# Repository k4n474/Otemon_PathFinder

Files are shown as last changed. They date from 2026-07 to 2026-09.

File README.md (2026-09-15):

# Otemon PathFinder

<p align="center">
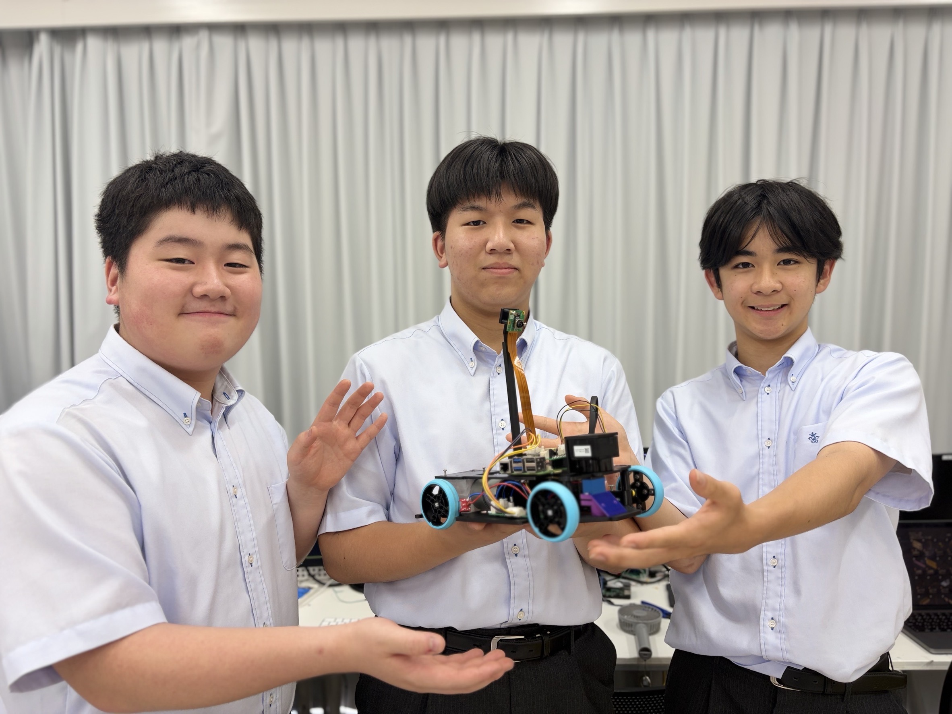
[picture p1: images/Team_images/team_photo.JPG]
team_photo
  
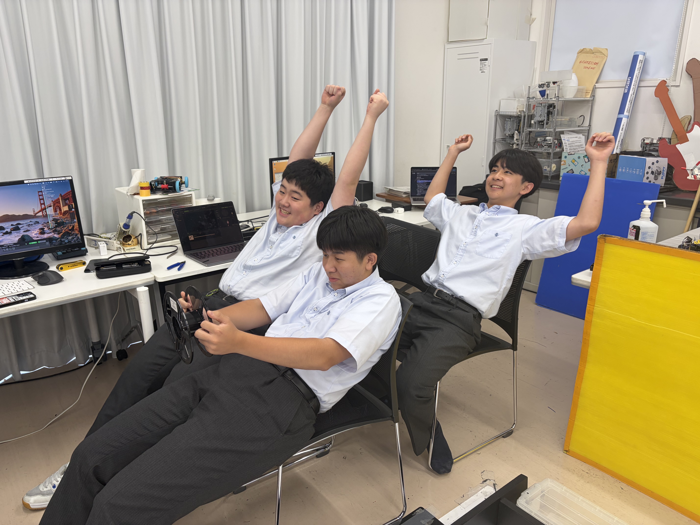
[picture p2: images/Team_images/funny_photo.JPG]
funny_photo
  
</p>

Meet the Engineers

(👈Left) [Name] led the mechanical design, crafting custom 3D-printed chassis parts, high-precision gears, and robust structural mechanisms.

(🫵Center) [Name] spearheaded the electrical architecture, designing custom PCBs, optimizing power management, and selecting core components.

(👉Right) [Name] drove software development and computer vision, building algorithm, calibrating sensor inputs, and writing code to keep the robot fully autonomous.

- [Hardware](#hardware)

  - [Photos of Robots](#photos-of-robots)

  - [Videos](#videos)

  - [Main Components](#main-components)

  - [Controller](#controller)

  - [LiDAR](#lidar)

  - [Camera](#camera)

  - [Chassis](#chassis)

  - [Steering Mechanism](#steering-mechanism)

  - [Electrical System](#electrical-system)

- [Software](#software)

  - [Open Challenge](#open-challenge)

  - [Obstacle Challenge](#obstacle-challenge)

# Hardware

## Photos of Robots

<p align="center">
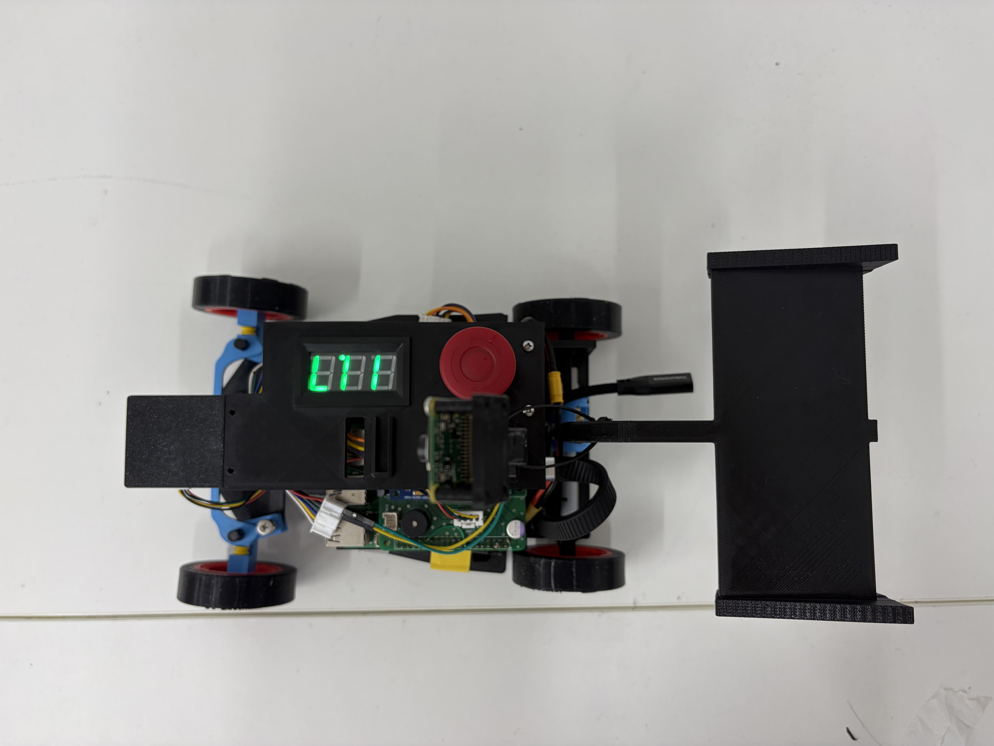
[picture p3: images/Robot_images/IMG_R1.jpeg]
Robot1
  
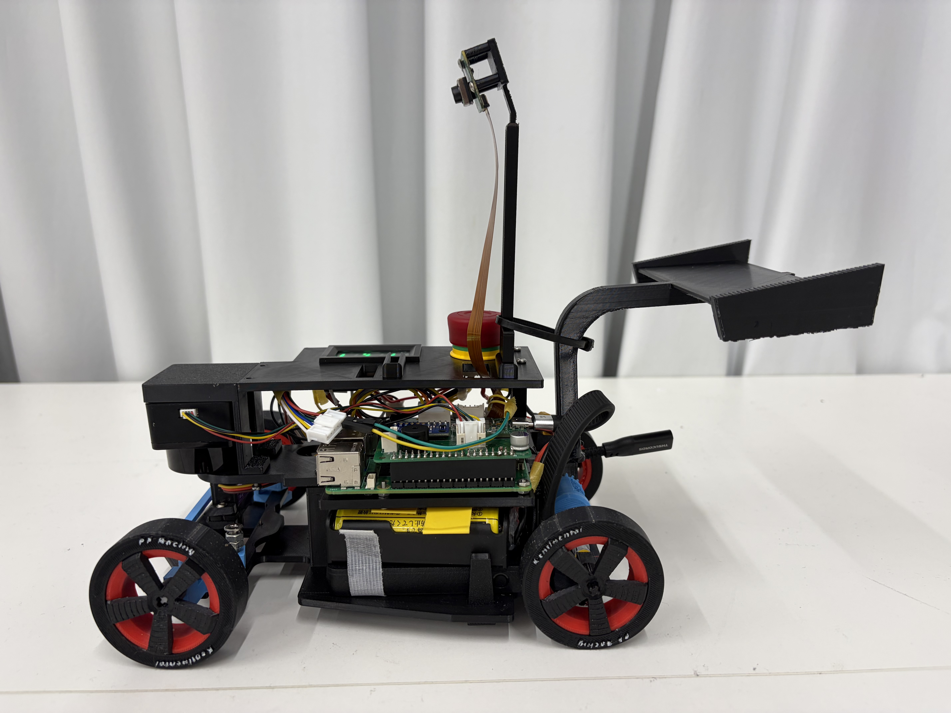
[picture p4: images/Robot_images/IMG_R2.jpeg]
Robot2
  
</p>

<p align="center">
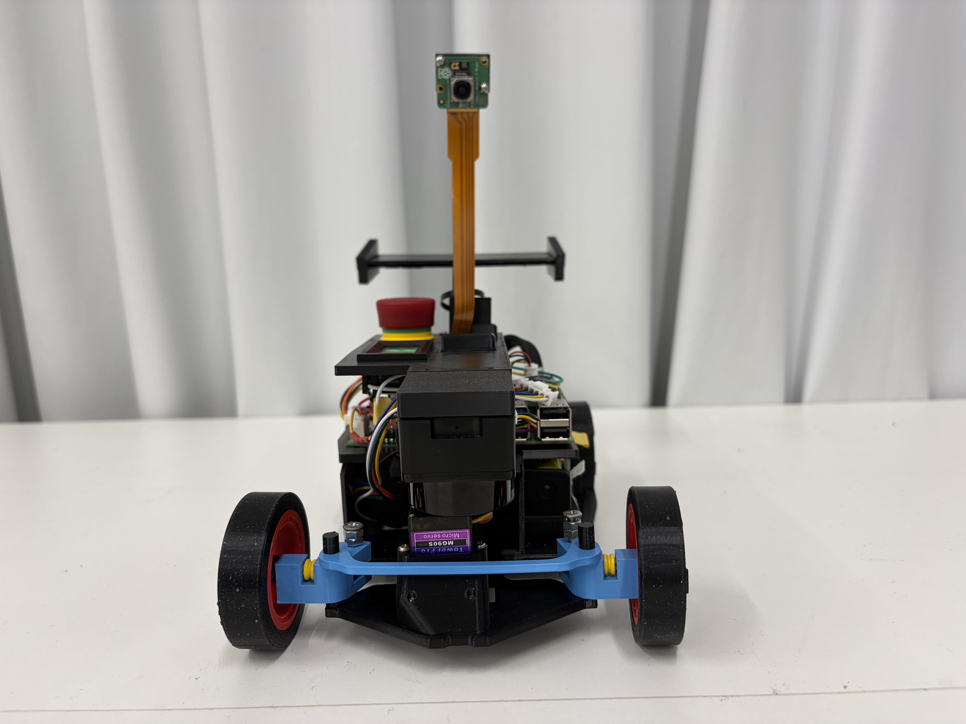
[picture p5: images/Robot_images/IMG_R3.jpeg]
Robot3
  
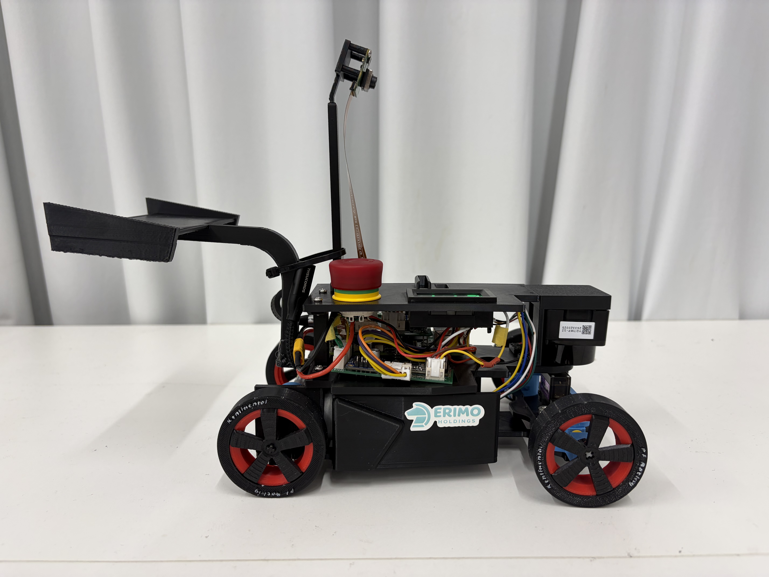
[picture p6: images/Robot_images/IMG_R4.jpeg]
Robot4
  
</p>

<p align="center">
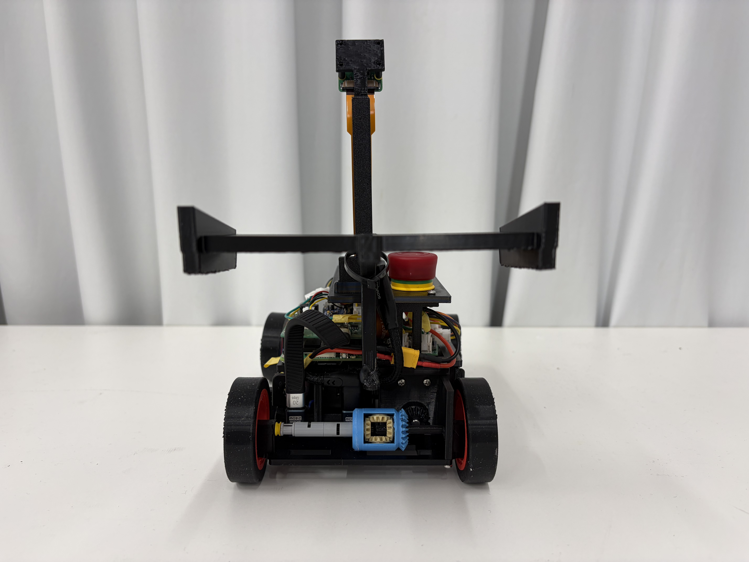
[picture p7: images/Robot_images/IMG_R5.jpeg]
Robot5
  
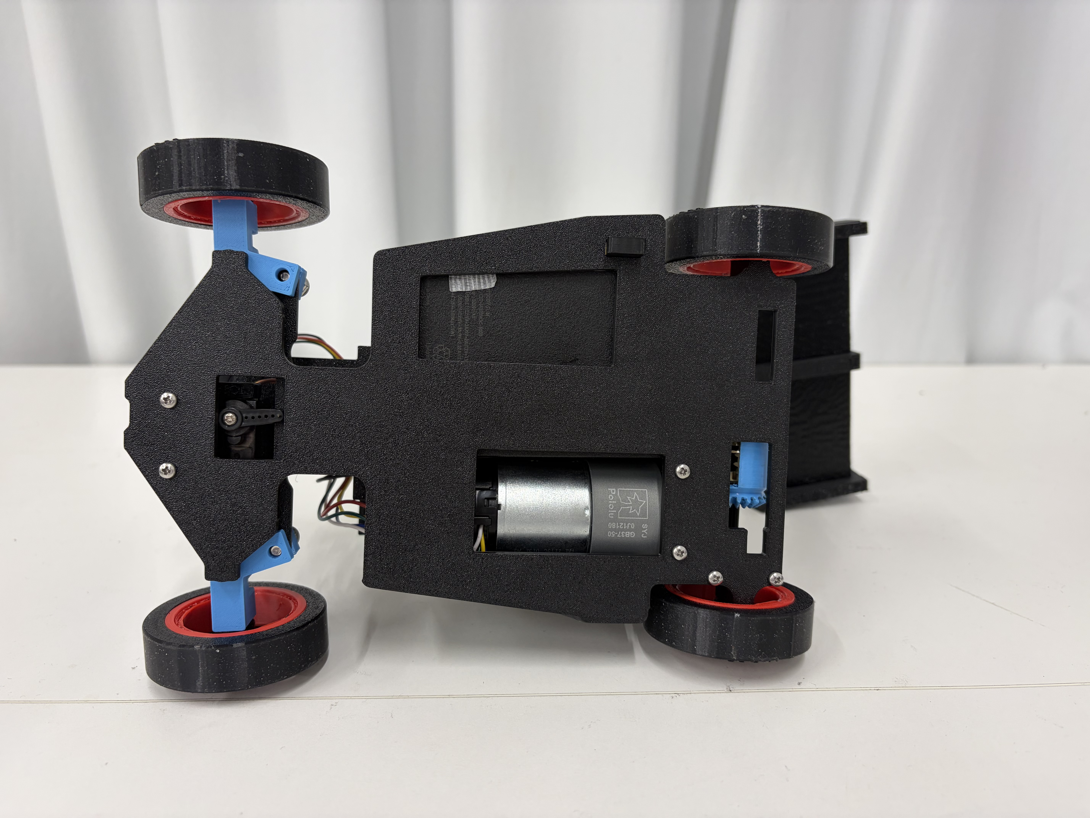
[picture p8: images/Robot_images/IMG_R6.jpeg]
Robot6
  
</p>

<p align="center">
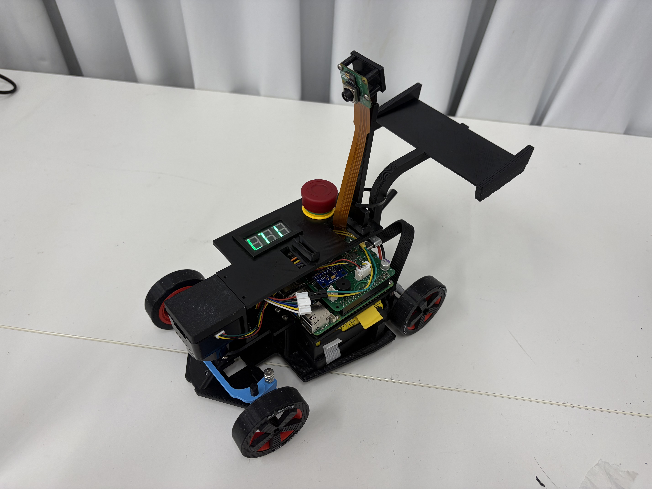
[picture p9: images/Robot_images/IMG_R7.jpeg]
Robot7
  
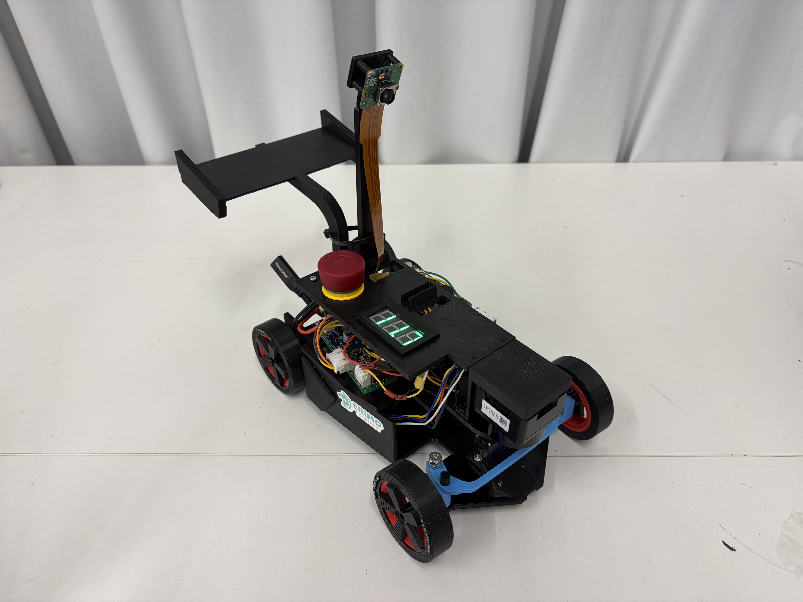
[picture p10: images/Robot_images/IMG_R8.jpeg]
Robot8
  
</p>

<p align="center">
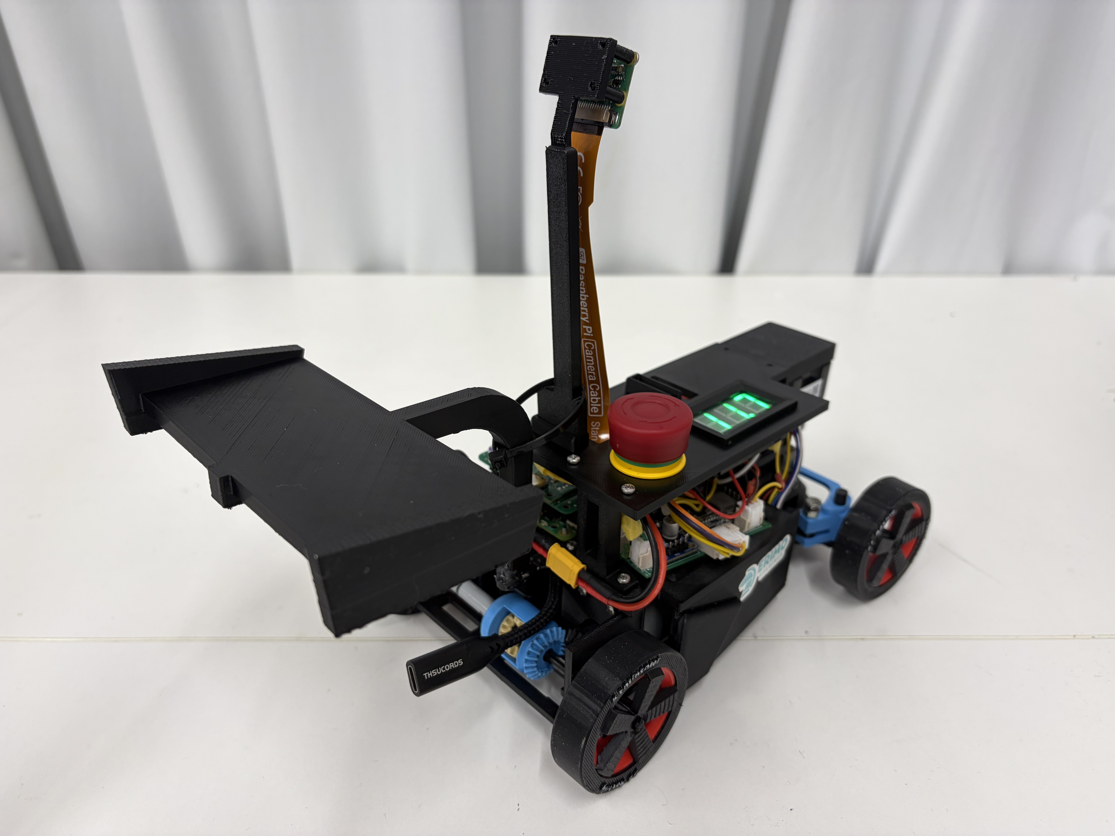
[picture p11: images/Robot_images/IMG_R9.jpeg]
Robot9
  
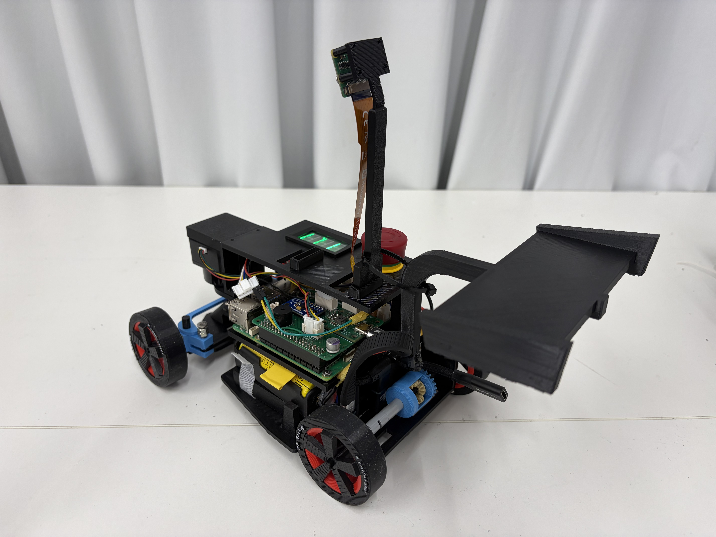
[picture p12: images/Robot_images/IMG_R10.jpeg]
Robot10
  
</p>

## Videos
<table align="center">
  <tr>
    <td align="center" width="50%">
      <a href="https://youtu.be/6eP5m4vgBc8">
        <br>
        <sub><b>Open_ChallengeCounter-clockwise</b></sub>
      </a>
    </td>
    <td align="center" width="50%">
      <a href="https://youtu.be/HAOU7pk2X0k">
        <br>
        <sub><b>Open_Challenge_clockwise</b></sub>
      </a>
    </td>
  </tr>
  <tr>
    <td align="center" width="50%">
      <a href="https://youtu.be/kFfds26Y_WM">
        <br>
        <sub><b>Obstacle_ChallengeCounter-clockwise</b></sub>
      </a>
    </td>
    <td align="center" width="50%">
      <a href="https://youtu.be/7NU6L5QEaes">
        <br>
        <sub><b>Obstacle_Challenge_clockwise</b></sub>
      </a>
    </td>
  </tr>
</table>

## Main Components

| Category| Model | 
|---|---|
| Controller | Raspberry Pi 5 |
| Subcomputer| Seeed XIAO RP2040 |
| LiDAR | T-mini Plus 12 |
| Camera | Camera Module 3 Wide |
| DC Motor | Pololu 50:1 Metal Gearmotor 37Dx70L mm 12V with 64 CPR Encoder (Helical Pinion) |
| Motor Driver | DRV8871 | 
| Servo Motor | MG90S |
| USB PD Power Supply | PWR-USBDCDC5 |
| Connectors | JST XA Series　|

## Controller

Our robot uses a **Raspberry Pi 5** as its main controller.

To accurately recognize objects, the robot must process camera images while simultaneously handling data from multiple sensors, including a LiDAR and a gyroscope. Therefore, we selected the Raspberry Pi because of its high computing performance and excellent expandability.

Unlike a conventional microcontroller, the Raspberry Pi is a compact computer that runs Linux. As a result, it is less suitable for applications requiring strict real-time control, such as motor control, and it also consumes more power. However, its powerful processing capability allows it to handle computationally intensive tasks, including image processing and LiDAR point cloud processing. Since these functions are essential for our robot, we concluded that the Raspberry Pi was the most suitable controller.

At the beginning of development, we used a **Raspberry Pi 4**. However, image processing required more computational power than expected, making real-time control difficult in some situations. After upgrading to the Raspberry Pi 5(Jun. 2026), image processing became significantly faster, resulting in much more stable driving performance.

We also adopted an **RP2040** as a sub-controller for motor control.

Because the Raspberry Pi 5 runs Linux, when we command it (for example, changing PWM values or reading encoders in Python), many processes such as LiDAR processing, camera processing, and communication are running simultaneously. As a result, **the processing timing can drift slightly**. Considering this and maintainability, we decided to offload motor control to the RP2040.

## LiDAR

Our robot uses a **LiDAR** for wall detection, distance measurement, and wall following.

We initially considered using ultrasonic sensors. However, ultrasonic sensors can only measure distance in a single direction, whereas the LiDAR can obtain distance information from almost the entire surrounding area, although part of its field of view is blocked by components such as the Raspberry Pi. This allows the robot to detect obstacles in front while simultaneously measuring the distances to both side walls, enabling more accurate self-localization.

One of the greatest challenges during development was designing an algorithm capable of accurately detecting walls using LiDAR point cloud data. In addition, because the robot must process a large amount of distance data in real time, optimizing the processing speed was also a major challenge. Through repeated testing and refinement, we continuously improved both the algorithm and the software until the current system was completed.

Currently, for each full rotation of LiDAR data (angle and distance), we remove points behind the robot and points with abnormal distances, and convert points within 3 m into planar coordinates. Then, using RANSAC, we search for line-shaped point sets: we randomly choose two points to form a line, collect points within 50 mm of that line, and repeat this 100 times, selecting the line that gathers the most points. We then refine the line using the gathered points, and treat a segment as a wall if it has at least 10 points and a length of at least 100 mm. Up to four walls are detected. If the gap between points exceeds 250 mm, we treat them as separate clusters.
Among the detected walls, we select up to the three walls with the highest number of points and classify them into right wall / front wall / left wall based on the direction of the perpendicular from the LiDAR to the wall. If three walls are available, we assign right–front–left in order of angle. If only one or two are available, we assign roles based on which reference direction they are closest to. However, to be used as a front wall, the wall must be at least 500 mm long. Distances to walls are computed using the perpendicular distance from the LiDAR to the wall line, and we follow whichever side wall is longer. This recognition is performed every rotation, and we do not build a map by accumulating past point clouds.

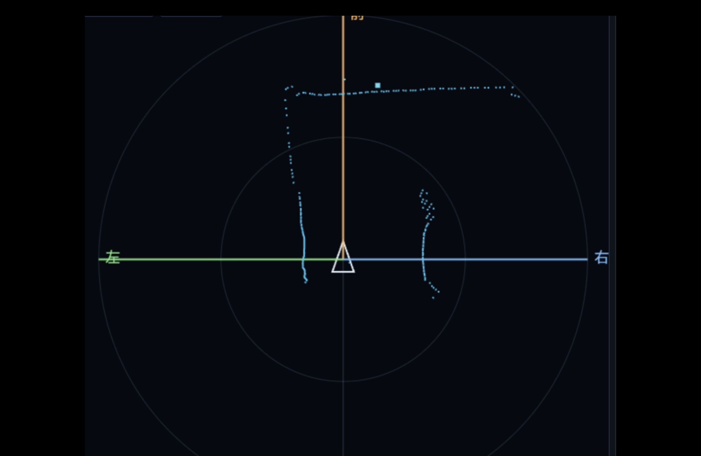
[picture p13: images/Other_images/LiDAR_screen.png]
LiDAR

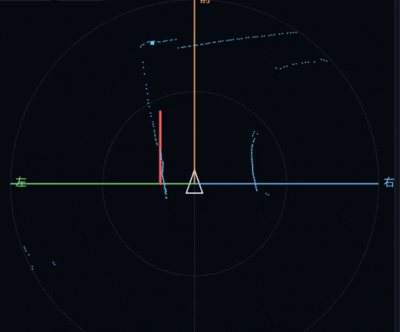
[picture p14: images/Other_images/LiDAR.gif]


## Camera

At the beginning of development, we used a **HuskyLens** because it allowed us to implement object recognition relatively easily. However, we found limitations in both recognition accuracy and flexibility, so we decided to develop our own image recognition program from scratch.

We use a **Raspberry Pi Camera Module 3 Wide** because of its excellent compatibility with the Raspberry Pi and its ability to capture images at high speed. Initially, we used the standard **Raspberry Pi Camera Module 3**, but its horizontal field of view was only about **66°**, causing obstacles to occasionally move outside the camera image. As a result, reliable obstacle avoidance was difficult. After replacing it with the **Camera Module 3 Wide**(Jun. 2026), the horizontal field of view increased to approximately **102°**, allowing the robot to detect obstacles much more reliably.

The captured RGB image is first converted into the **HSV color space**. HSV consists of **Hue (color), Saturation, and Value (brightness)**, and is less affected by changes in lighting conditions than RGB. This enables the robot to distinguish red and green objects more reliably by using hue information.

<p align="center">
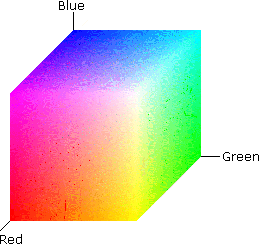
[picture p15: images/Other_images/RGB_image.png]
rgb
  
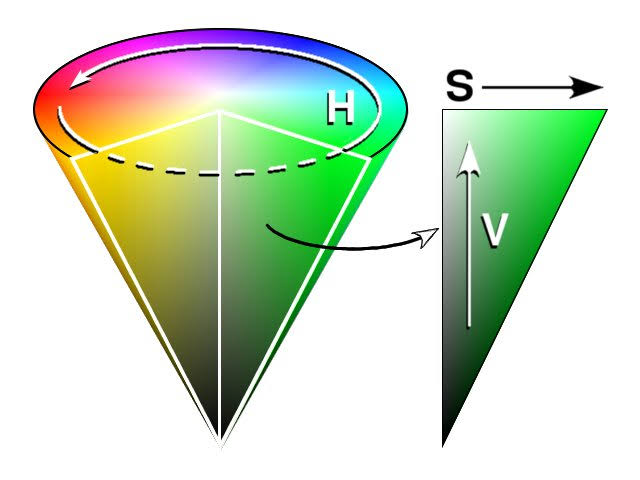
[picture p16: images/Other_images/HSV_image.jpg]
hsv
  
</p>

After the conversion, separate color masks are applied to the red and green objects, followed by binary thresholding to extract only the target objects. Contour detection is then performed to obtain the coordinates of the four corners of each object. However, with this approach alone, the system also recognized red and blue objects outside the coat. Therefore, we modified the system so that it would recognize the coat using the camera and treat only objects overlapping that area as obstacles(Aug. 2026).Using those object coordinates, we determine the objects’ positions and colors, and use the resulting information for navigation.Also, since part of the robot appears in the camera's field of view, the program is configured to skip image recognition in that area.

The court is detected using the same approach as object detection, by applying a white color mask.

<p align="center">
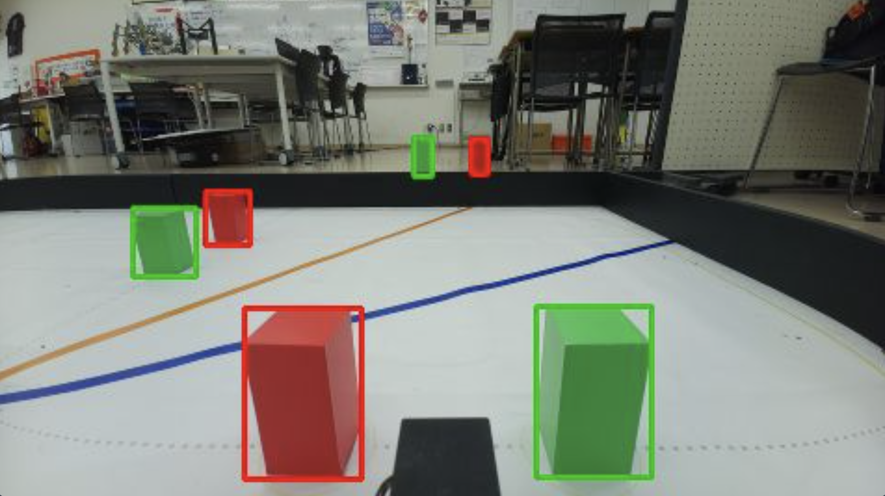
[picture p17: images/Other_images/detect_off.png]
off
  
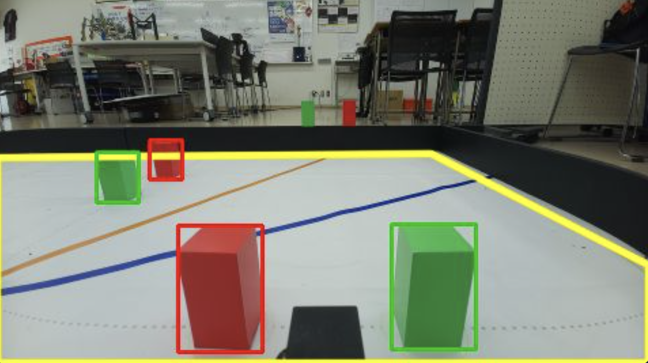
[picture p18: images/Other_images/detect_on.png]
on
  
</p>

In addition, the camera recognizes a blue line to count the number of laps.

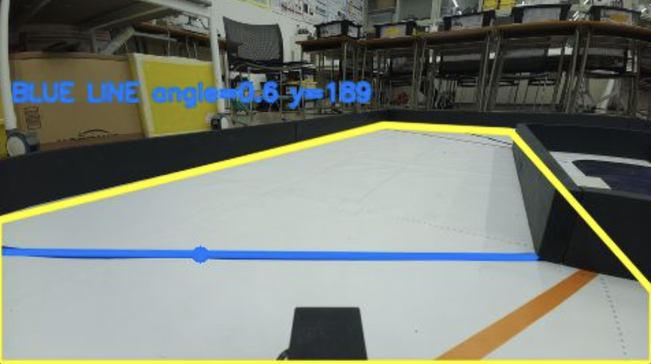
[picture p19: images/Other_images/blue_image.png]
Camera


## Chassis

Most of the robot’s mechanical components, excluding electronic parts, were designed by our team and manufactured using **3D printers**. This allowed us to create custom parts that would have been difficult or impossible to produce using commercially available components, enabling a structure optimized specifically for our robot.

We selected **ABS** as the printing material. At the beginning of development, we used PLA and PETG because they were easier to print, but we decided to switch to ABS due to durability concerns(Aug. 2026).

We use a **Bambu Lab X2D** for manufacturing. At the beginning of development, all parts were produced using a **Bambu Lab A1**. However, the A1 could not print ABS, so we introduced the X2D to enable ABS printing(Jul. 2026). In addition, the **Bambu Lab X2D** improved printing speed and quality.

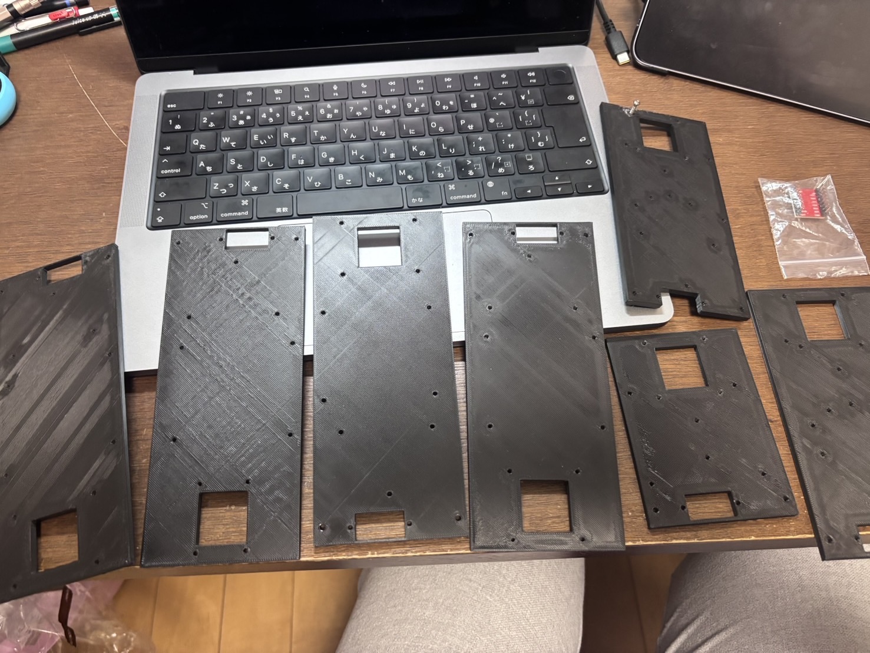
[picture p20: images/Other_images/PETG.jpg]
PETG

This is the PETG chassis from an early version of our robot. All parts have been fine-tuned.

## Steering Mechanism

Initially, our robot used a conventional steering mechanism. However, it could not achieve sufficient turning performance when negotiating sharp corners.

To improve cornering performance, we adopted an **Ackermann steering mechanism** for the front wheels.(Jun. 2026) This allows each front wheel to follow the appropriate turning radius while sharing the same turning center, reducing tire slip and enabling smoother cornering.

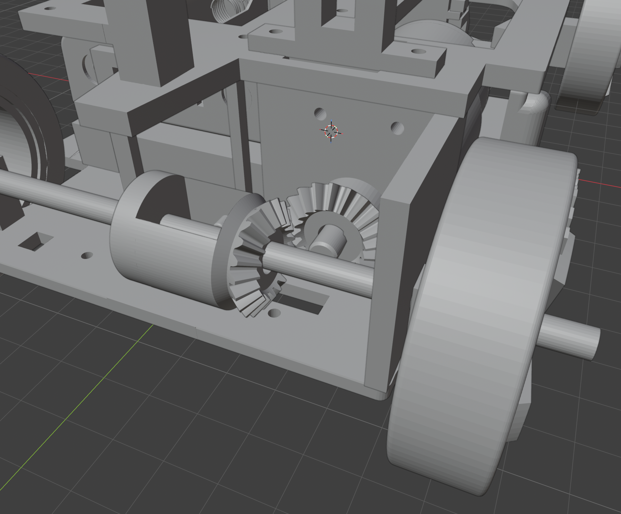
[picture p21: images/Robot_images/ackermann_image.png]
Ackermann


In addition, we selected **high-torque drive motors**, providing sufficient driving force even under heavy loads and ensuring stable vehicle movement.

A **differential gear** is also installed on the rear axle.(Jun. 2026) During cornering, it absorbs the rotational speed difference between the left and right wheels, reducing mechanical stress on the tires and enabling smoother turns.

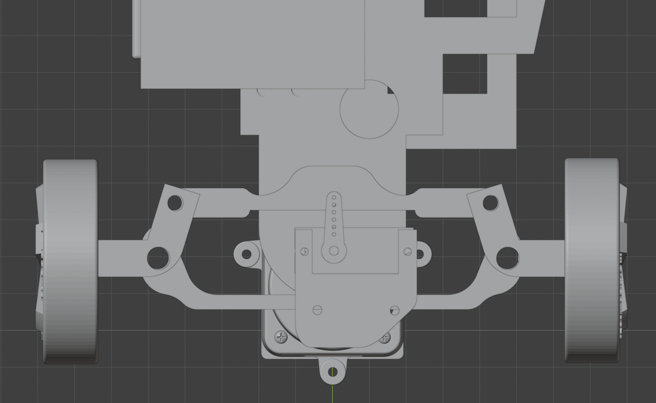
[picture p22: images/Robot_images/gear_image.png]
Gear


## Electrical System

To prevent voltage drops and electrical noise generated by the drive motors from affecting the control system, our robot uses **separate power supplies for the drive system and the control system.**

The drive motors are powered by a battery pack consisting of **three 18650 lithium-ion batteries connected in series**. Since the fully charged battery voltage is approximately **12 V**, the motors are powered directly without additional voltage conversion.

When the voltage drops below 11 V, the robot’s movement becomes weaker. Therefore, we installed a voltmeter module on the robot to monitor the voltage(Sep. 2026).

In addition, to allow the robot to stop immediately in dangerous situations (for example, when it starts malfunctioning), we added an emergency stop button to the motor power circuit so that the robot can be stopped physically(Sep. 2026).

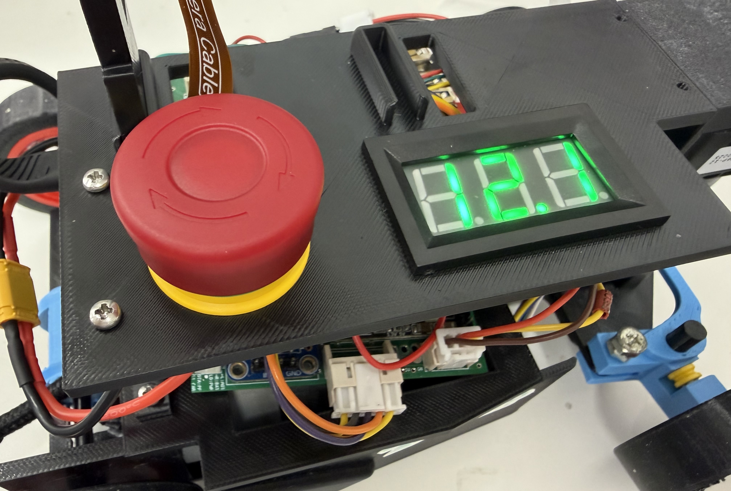
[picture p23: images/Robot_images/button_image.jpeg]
Stop_button


The steering servo is powered through a **buck converter (DC-DC converter)**, which steps the voltage down to **5 V** and provides a stable power supply.

The Raspberry Pi is powered by a **5,000 mAh USB Power Delivery (PD) power bank**. Separating the motor and control power supplies reduces malfunctions caused by voltage fluctuations and electrical noise, significantly improving the overall stability of the robot.

To simplify wiring as additional functions were added, we also designed and manufactured a **custom Raspberry Pi HAT board**(Jun. 2026). This board organizes the wiring, simplifies assembly and maintenance, and improves the overall maintainability of the robot.

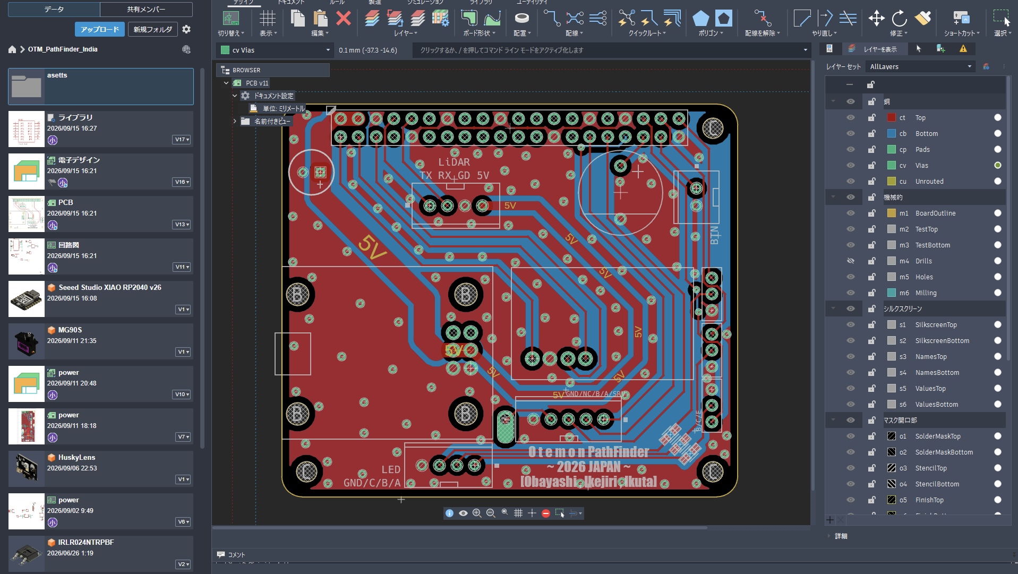
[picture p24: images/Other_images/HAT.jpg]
HAT


### Overall Wiring

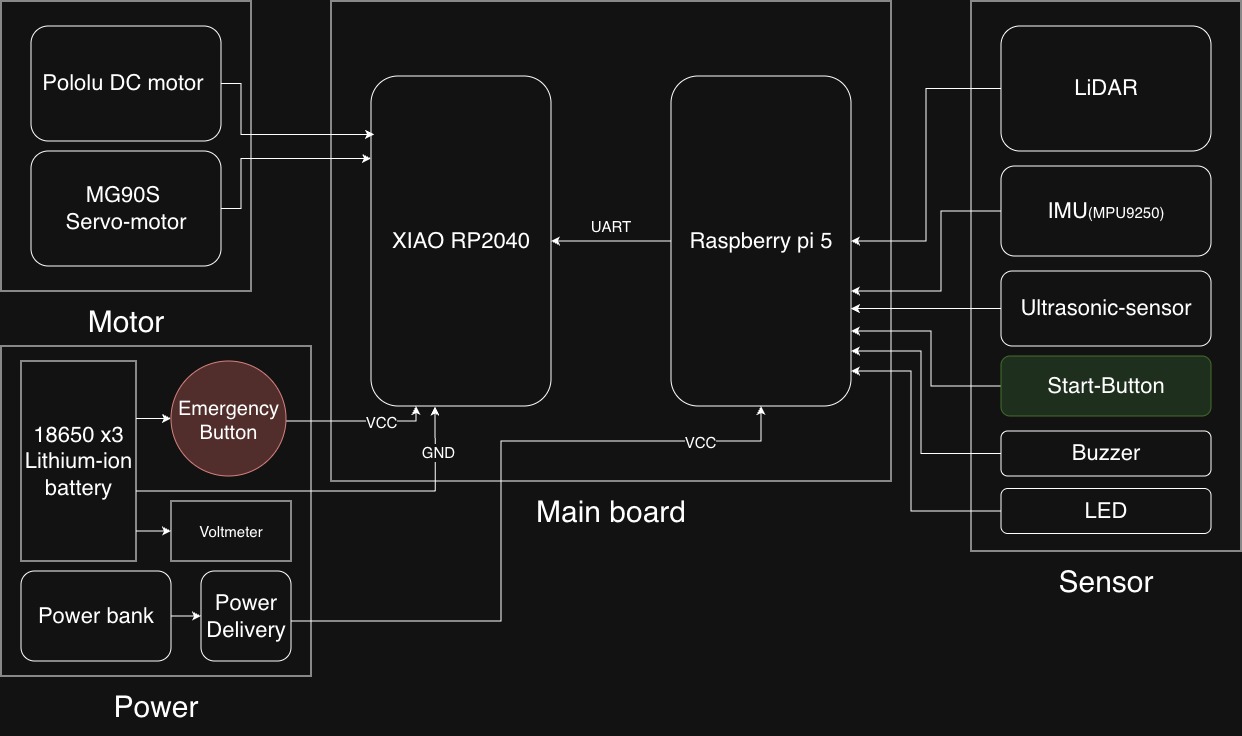
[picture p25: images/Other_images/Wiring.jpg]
Wiring


# Software

## Open Challenge

In the **Open Challenge**, the robot navigates primarily using **LiDAR**. As described earlier, we selected LiDAR because it provides distance information from almost the entire surrounding area, allowing the robot to perceive its environment with high accuracy.

During operation, the robot continuously measures the distances to the front wall and both side walls using the LiDAR. The distances to the side walls are used as the input for a **PID controller**, enabling the robot to maintain a stable position near the center of the course. In addition, at the start the robot detects the left and right walls using LiDAR, and leveraging the characteristic that the field’s inner wall is shorter than the outer wall, it decides which wall to follow based on wall length.

Just before a corner, when the distance to the front wall falls below a predefined threshold, the robot determines that it has reached the corner. It then measures the angle of the front wall with LiDAR and determines (with a gyroscope) the angle that becomes parallel to the front wall while performing the turn. This feedback-based control allows the robot to achieve stable and accurate cornering.

## Obstacle Challenge

In the **Obstacle Challenge**, the robot uses a **Raspberry Pi Camera** to detect obstacles and control its movement accordingly.

The obstacle-avoidance loop begins by checking whether an object is detected by the camera. If no object is detected, the robot repeatedly runs `find_obj` until an object is found. `find_obj` basically steers in the same direction as the lap direction while moving forward until an object is detected. However, if a wall is detected using the line at the bottom of the camera image, it interrupts this behavior and steers away from the wall until the wall is no longer detected.

Once an object is detected, the robot starts `avoid_obj` to avoid the closest object. The closest object is defined as the one appearing lowest in the image.

In `avoid_obj`, the robot avoids **red** objects by going to the right and **green** objects by going to the left. If the object being avoided disappears from the camera image and no other objects are detected, the robot returns to `find_obj`. If other objects are still detected, the robot continues `avoid_obj`, and the next closest object becomes the new target without leaving the function.

For example, if the object is green, the robot draws a line from the bottom-right corner of the image to the center of the green object, and uses PD control on the steering so that the angle inside that line matches a preset value. During `avoid_obj`, another line is drawn from the bottom-right corner to a point slightly left of the object’s left edge (object width × 3 px). This line corresponds to the path of the robot’s right edge while avoiding the object. If this line overlaps with a wall, the robot would collide with the wall if it continued, so it temporarily stops the avoidance PID control and steers left until the wall no longer overlaps with the wall-detection line. (For red objects, the left/right behavior is reversed.)

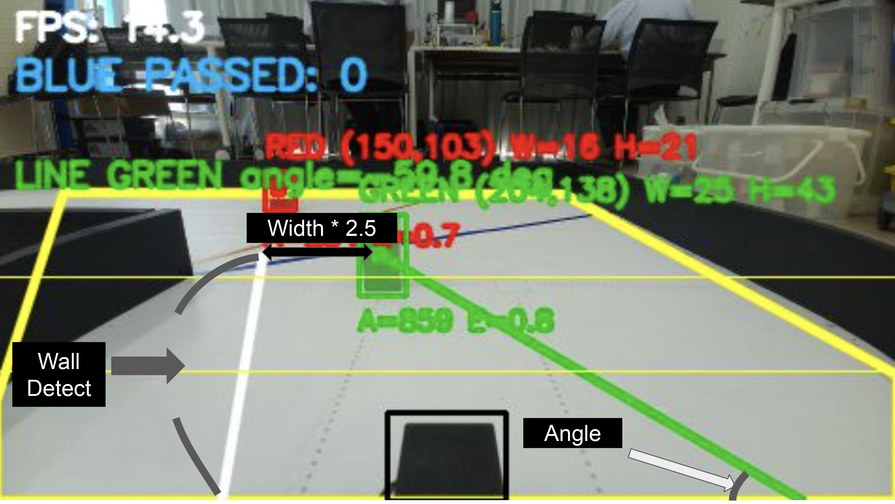
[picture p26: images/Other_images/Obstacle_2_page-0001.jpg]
Obstacle_image

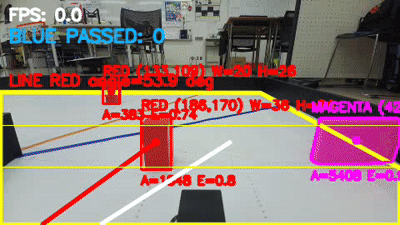
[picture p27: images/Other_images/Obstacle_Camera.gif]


Lap counting is done by counting how many times the blue line is detected. When the blue line transitions from detected to not detected, the lap count is incremented by 1. For a few seconds after detecting the blue line, detections are ignored to prevent false double-counting when the same line briefly disappears and reappears in the camera view.

Since our robot is relatively large, it often hits the wall when starting and when parking. As a result, the start succeeded only 7 out of 10 times and parking succeeded only 4 out of 10 times, which corresponds to success rates of 70% and 40%, respectively. Considering that the scores are 7 points for starting and 15 points for parking, we concluded that it is not worth attempting them at these success rates, and we decided to give up on starting and parking.

### Flowchart
<p align="center">
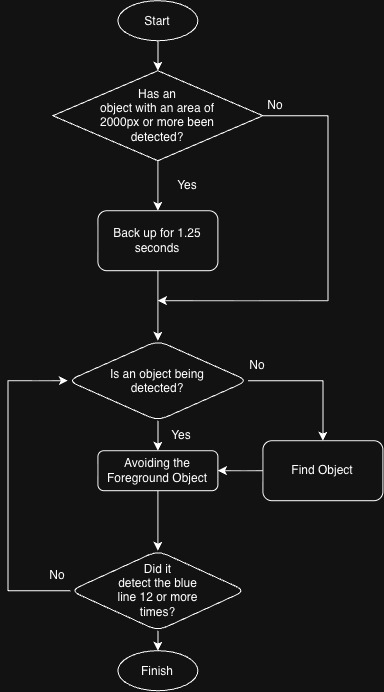
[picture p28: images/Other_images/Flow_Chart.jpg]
Flow_Chart
  
</p>

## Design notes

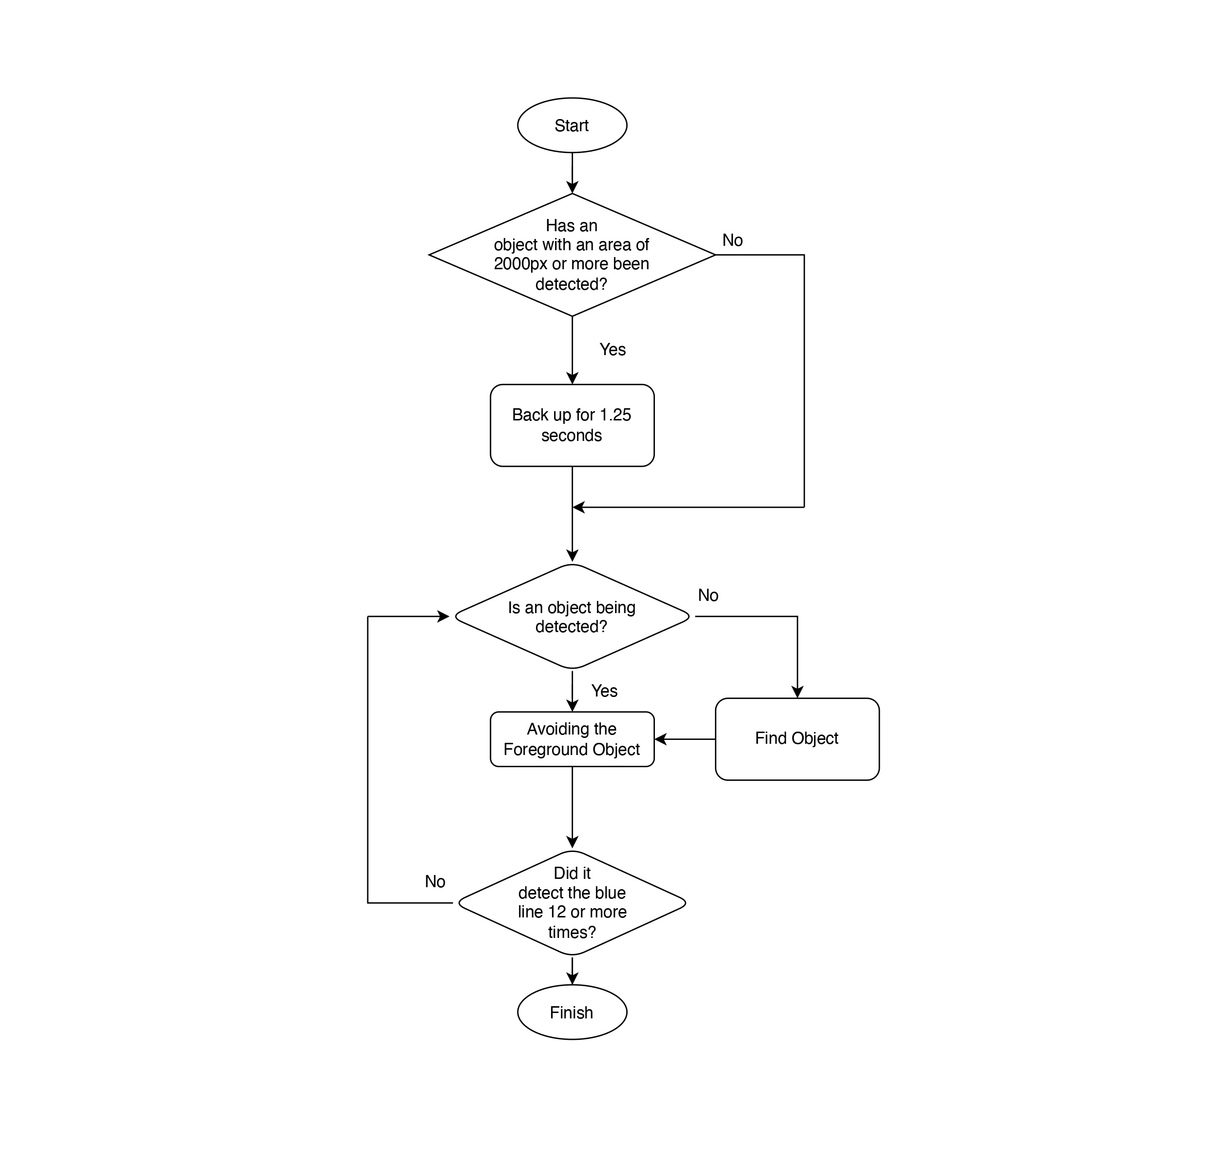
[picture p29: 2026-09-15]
images/Other_images/flow_chart_page-0001.jpg

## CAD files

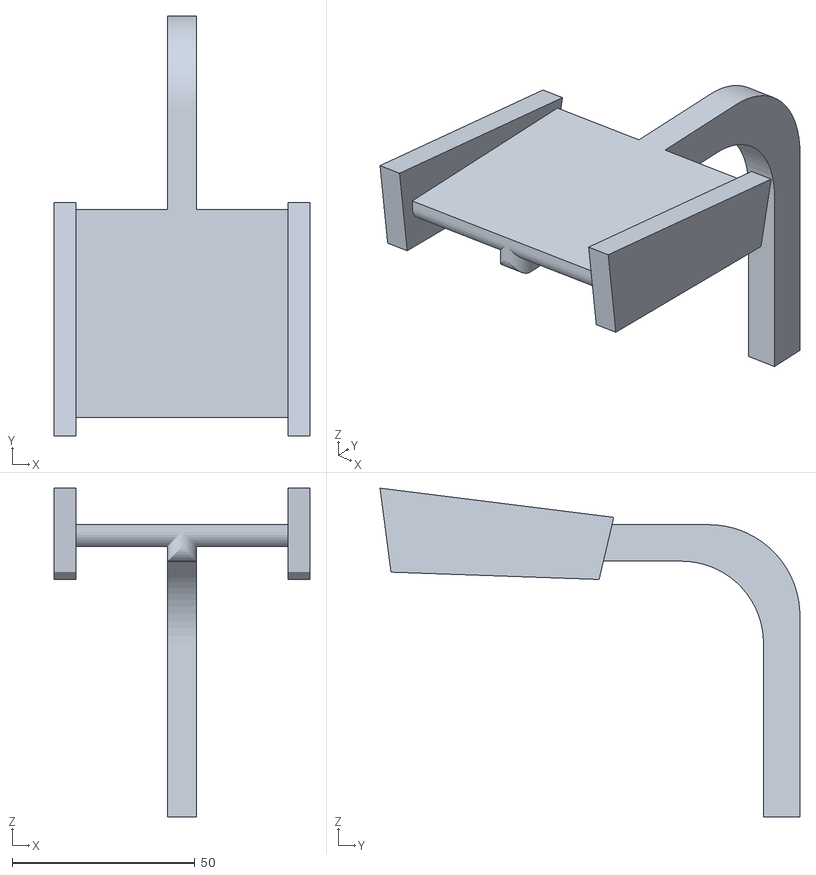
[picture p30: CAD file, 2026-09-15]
CAD/GTWing.stl
70.0 x 115.0 x 90.0

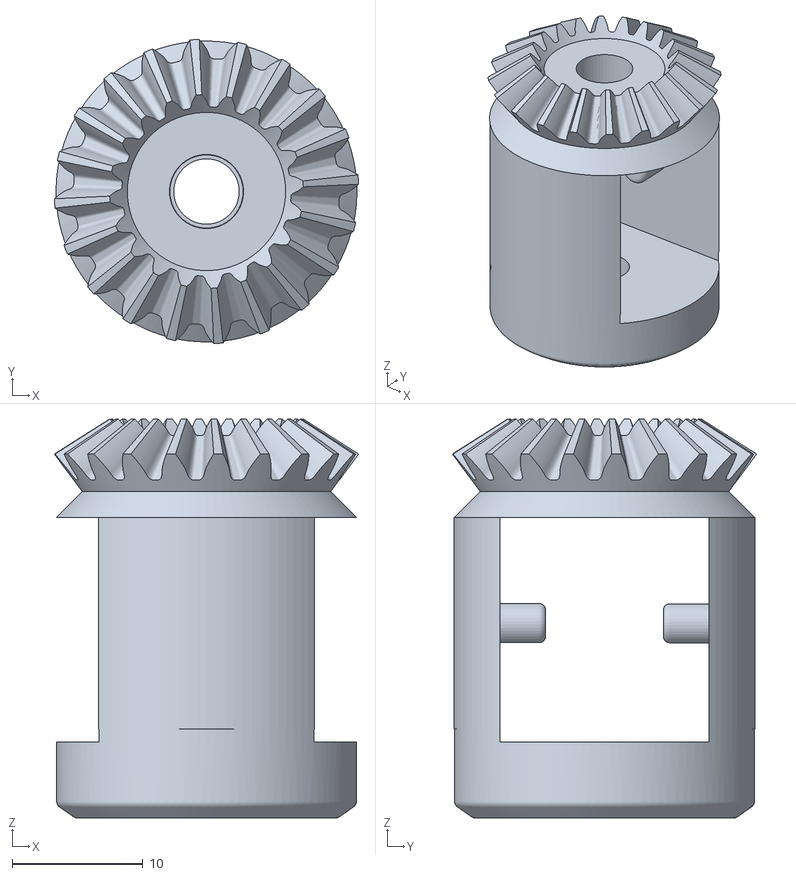
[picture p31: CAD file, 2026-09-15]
CAD/DiffinitialGear.stl
23.3 x 23.3 x 30.5

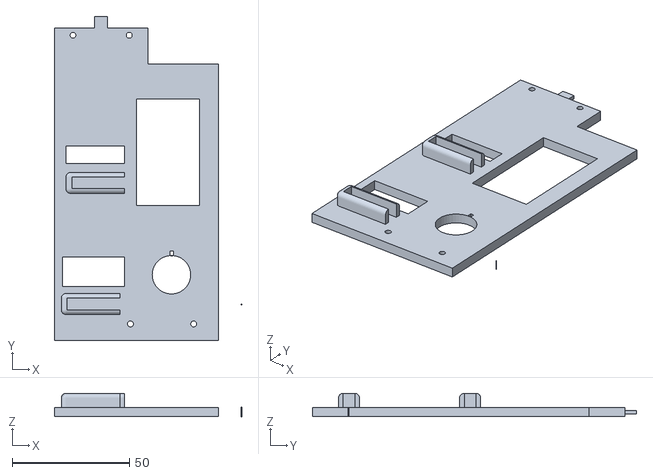
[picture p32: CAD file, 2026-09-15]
CAD/sansoume.stl
80.0 x 138.3 x 10.0

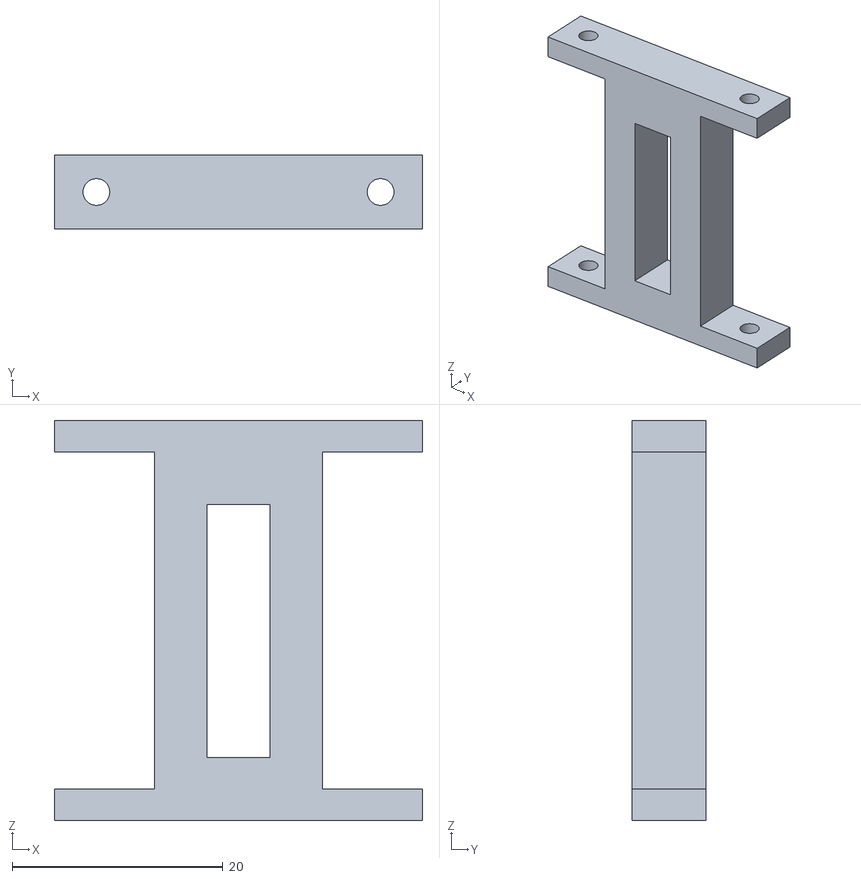
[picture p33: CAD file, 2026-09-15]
CAD/sasae.stl
35.0 x 7.03 x 38.0

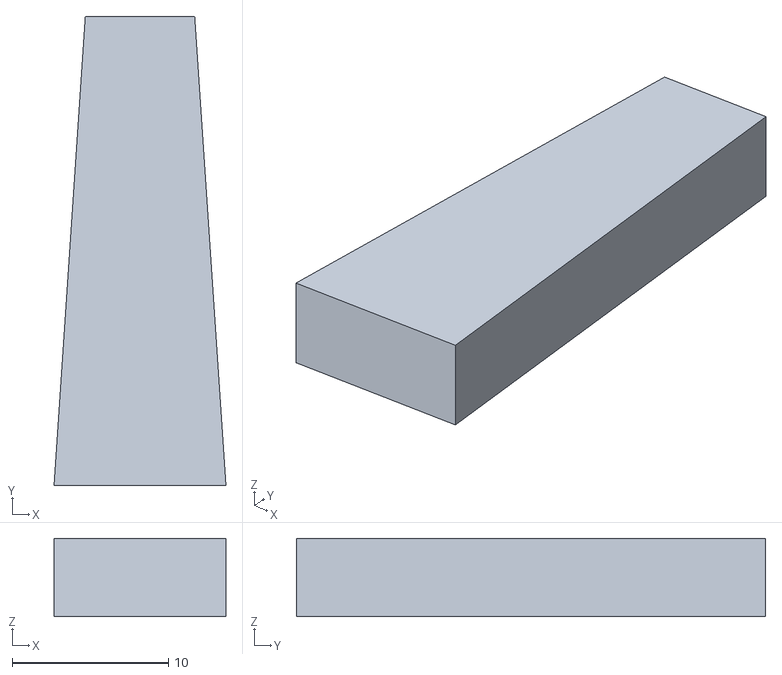
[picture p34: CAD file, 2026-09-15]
CAD/Stoper.stl
11.0 x 30.0 x 5.00

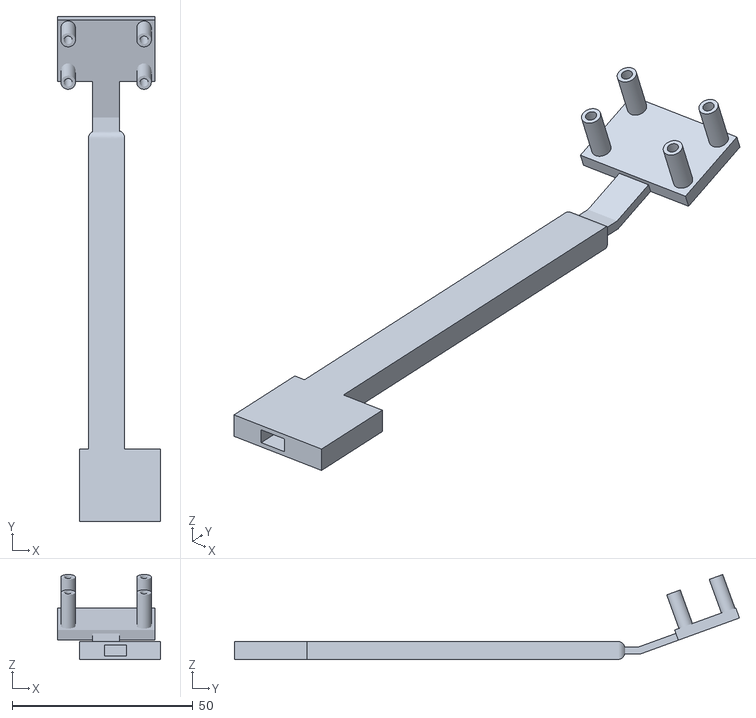
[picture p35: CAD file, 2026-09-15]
CAD/Camera.stl
28.6 x 139.7 x 23.5

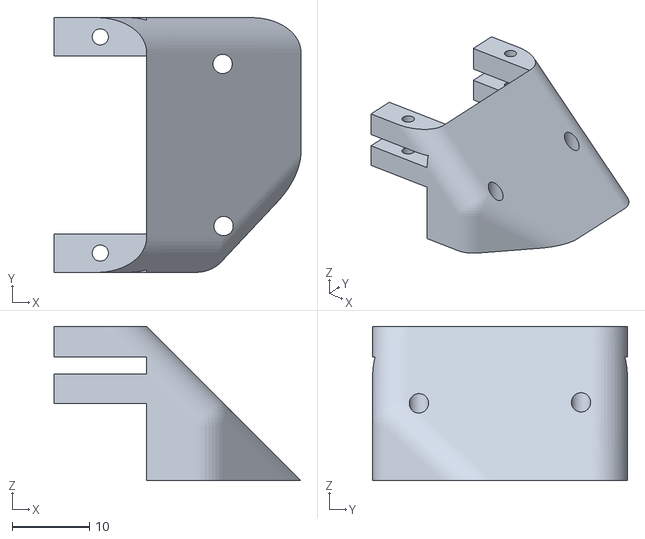
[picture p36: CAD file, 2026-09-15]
CAD/Servo-Mount.stl
32.0 x 33.0 x 20.0

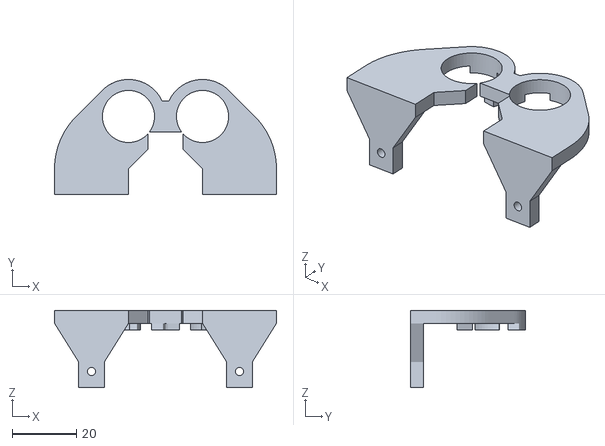
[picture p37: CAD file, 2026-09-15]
CAD/Ultra sensor.stl
69.0 x 35.8 x 24.0

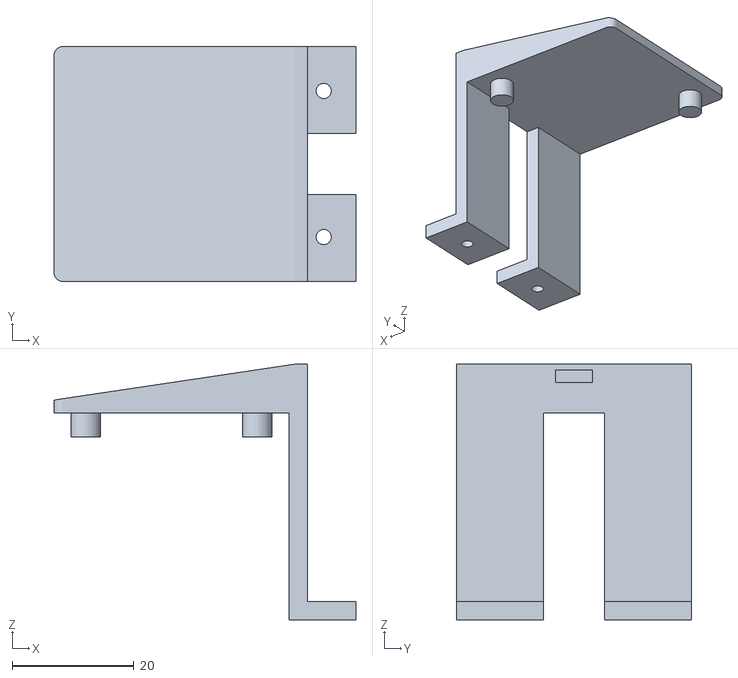
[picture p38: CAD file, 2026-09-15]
CAD/LiDARー.stl
49.6 x 38.6 x 42.0

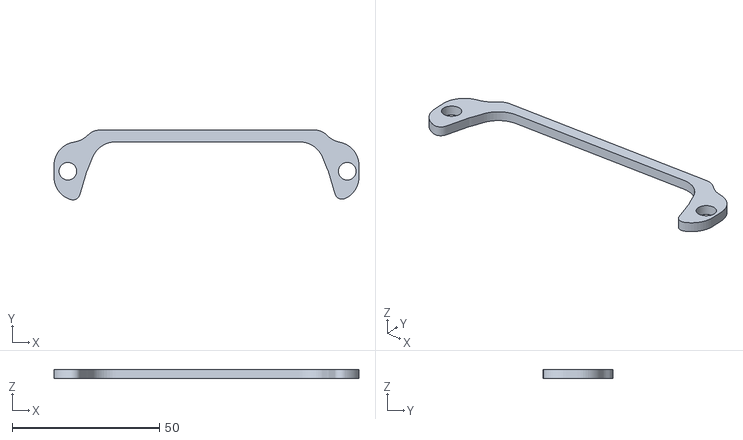
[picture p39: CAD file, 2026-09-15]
CAD/Zenrin dome.stl
103.7 x 23.8 x 3.00

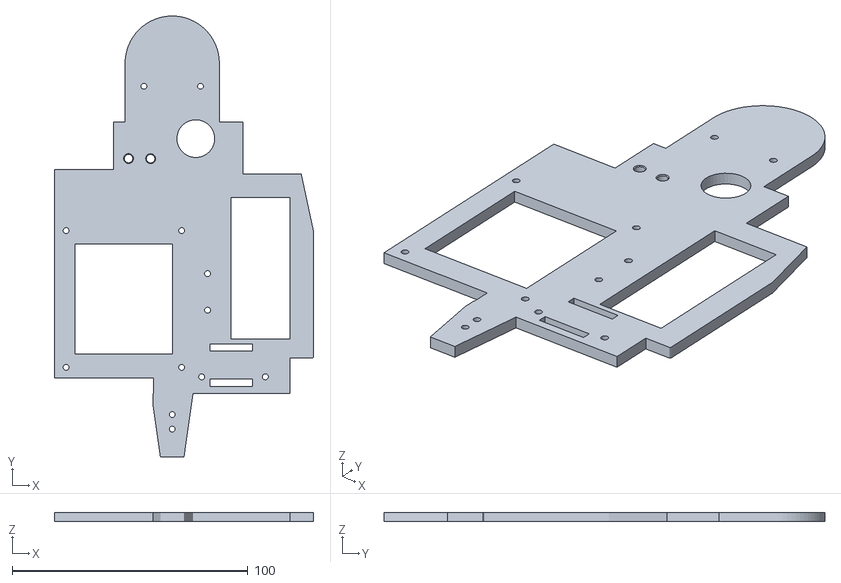
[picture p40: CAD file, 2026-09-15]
CAD/nisoume.stl
110.0 x 187.0 x 4.00

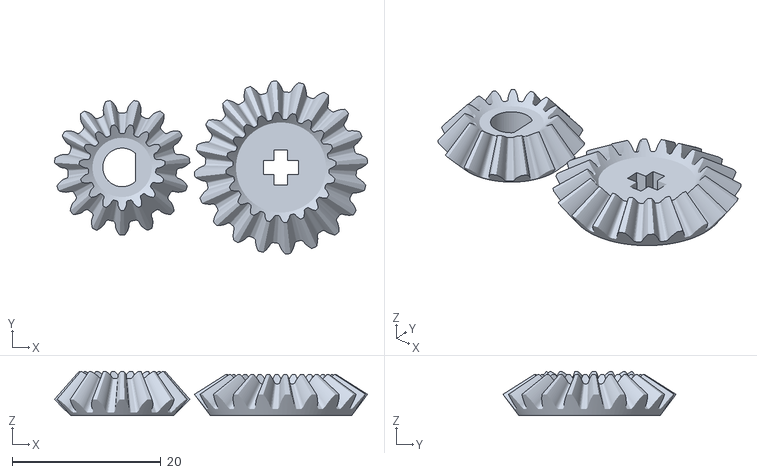
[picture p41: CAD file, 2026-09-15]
CAD/Gear.stl
42.1 x 23.3 x 5.95

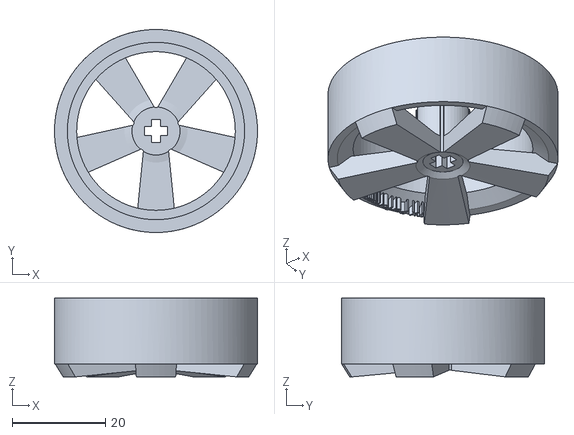
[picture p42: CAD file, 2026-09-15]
CAD/Wheel.stl
43.5 x 43.5 x 16.9

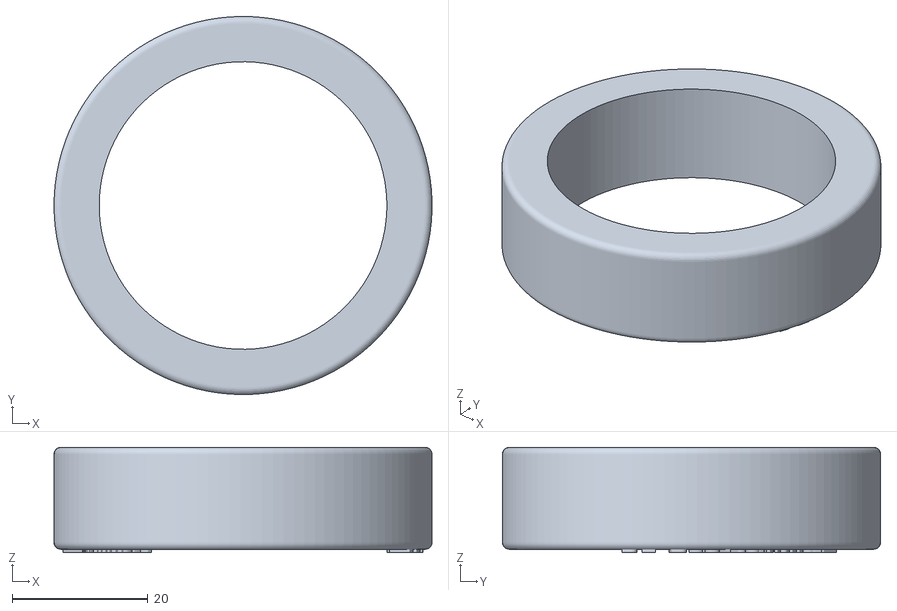
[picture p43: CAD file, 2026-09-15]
CAD/Tires.stl
55.6 x 55.6 x 15.5

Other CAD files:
CAD/PF-R4.stl
CAD/OPF Gen2 Evo Chassis.stl
CAD/PF-R4_Ackermann_s.stl
CAD/PF-R4_gearbox.stl

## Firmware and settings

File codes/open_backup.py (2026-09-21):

"""Select the longest side wall and follow it at the configured target distance."""
import time
import RPi.GPIO as GPIO
from threading import Event, Lock, Thread

from flask import Flask, jsonify, send_from_directory
from flask_cors import CORS

from algorithm import (
    detect_corners,
    detect_front_and_side_walls,
    detect_walls
)
from gyro import close_gyro, get_angle, reset_angle
from lidar_read import LidarReader
from lidar_wall_follow import WallPIDController
from newobot import cleanup, dc_motor, set_angle, stop


# Target distance from the followed wall, in millimeters.
TARGET_DISTANCE = 280
# Distance used to check the shorter wall at the start, in millimeters.
START_SHORTER_WALL_DISTANCE = 300
# Ignore front-wall control decisions briefly after the initial reverse.
START_REVERSE_FRONT_IGNORE_SECONDS = 2.5
# DC motor power during normal driving.
MOTOR_SPEED = 42
# DC motor power during turns.
TURN_MOTOR_SPEED = 50
# Proportional gain for wall-distance error.
STEERING_KP = 0.05
# Integral gain for wall-distance error.
STEERING_KI = 0#0.01
# Derivative gain for wall-distance error.
STEERING_KD = 0.1#0.06
# Maximum steering angle during wall following, in degrees.
MAX_STEERING_ANGLE = 30.0
# Clamp the accumulated error to prevent integral windup.
INTEGRAL_LIMIT = 800
# Interval between LiDAR reads and control updates, in seconds.
INTERVAL = 0.1
# Front-wall distance that triggers a turn, in millimeters.
FRONT_WALL_TURN_DISTANCE = 380
# Front-wall distance at which the turn angle is fixed, in millimeters.
FRONT_WALL_PLAN_DISTANCE = 800
# Fixed steering-angle magnitude during a turn, in degrees.
TURN_STEERING_ANGLE = 31
# Subtract this correction from the wall-derived target turn angle, in degrees.
TURN_ANGLE_REDUCTION = 5.0
# Ignore target turns smaller than this angle, in degrees.
MIN_TURN_TARGET_ANGLE = 40.0
# Maximum allowed turn duration, in seconds.
TURN_TIMEOUT = 20.0
# Keep the robot stopped for this long after a turn, in seconds.
TURN_END_STOP_SECONDS = 1.0
# Wait for fresh LiDAR readings before selecting the wall to follow.
TRACE_SELECTION_WAIT_SECONDS = 1.0
# Number of turns treated as three completed laps.
MAX_TURN_COUNT = 12
# Driving time after the final turn before checking the front stop distance, in seconds.
FINAL_RUN_STRAIGHT_SECONDS = 2.0
# Front-wall distance at which to stop after three laps, in millimeters.
FINAL_STOP_FRONT_DISTANCE = 1450
# Wait this long after turning before locking wall roles again, in seconds.
WALL_ROLE_LOCK_DELAY = 2.0
# Ignore front-wall detections briefly after a turn to avoid retriggering, in seconds.
FRONT_WALL_IGNORE_AFTER_TURN_SECONDS = 2.0


viewer_app = Flask(__name__)
CORS(viewer_app)
viewer_lock = Lock()
viewer_previous_update = None
viewer_data = {
    "count": 0,
    "fps": 0.0,
    "points": [],
    "wall_count": 0,
    "walls": [],
    "corner_count": 0,
    "corners": [],
    "front_wall_detected": False,
    "front_wall": None,
    "side_walls": {
        "left": None,
        "right": None,
        "trace": None
    },
    "gyro": {
        "ready": False,
        "yaw": None,
        "error": None
    },
    "turn": {
        "status": "waiting",
        "active": False,
        "direction": None,
        "target_angle": None,
        "turned_angle": 0.0
    }
}


@viewer_app.get("/")
def viewer_home():
    """Serve the Live Viewer page from the same server as the API."""
    return send_from_directory(viewer_app.root_path, "index.html")


@viewer_app.get("/api/points")
def api_points():
    with viewer_lock:
        return jsonify(viewer_data)


def start_viewer_api():
    """Publish driving-time LiDAR results for the index.html Live Viewer."""

    viewer_app.run(
        host="0.0.0.0",
        port=5000,
        debug=False,
        threaded=True,
        use_reloader=False
    )


def update_viewer(points, walls, side_walls):
    global viewer_previous_update

    updated_at = time.monotonic()
    fps = 0.0

    if viewer_previous_update is not None:
        elapsed = updated_at - viewer_previous_update

        if elapsed > 0.0:
            fps = 1.0 / elapsed

    viewer_previous_update = updated_at
    front_wall = min(
        (
            wall
            for wall in walls
            if wall.get("is_front_wall")
        ),
        key=lambda wall: wall["front_distance"],
        default=None
    )
    corners = detect_corners(walls)

    with viewer_lock:
        viewer_data.update({
            "count": len(points),
            "fps": round(fps, 1),
            "points": points,
            "wall_count": len(walls),
            "walls": walls,
            "corner_count": len(corners),
            "corners": corners,
            "front_wall_detected": front_wall is not None,
            "front_wall": front_wall,
            "side_walls": side_walls
        })


def update_turn_viewer(
    active,
    direction,
    target_angle,
    turned_angle,
    status=None
):
    """Publish the current turn state to the Live Viewer."""

    with viewer_lock:
        viewer_data["turn"] = {
            "status": status or (
                "turning" if active else "completed"
            ),
            "active": active,
            "direction": direction,
            "target_angle": target_angle,
            "turned_angle": turned_angle
        }


def update_gyro_viewer():
    """Publish the current yaw angle and gyro read status to the Live Viewer."""
    try:
        yaw = round(get_angle("z"), 1)
        gyro_state = {"ready": True, "yaw": yaw, "error": None}
    except RuntimeError as error:
        gyro_state = {"ready": False, "yaw": None, "error": str(error)}

    with viewer_lock:
        viewer_data["gyro"] = gyro_state


def choose_turn_direction(_walls, _side_walls, trace_side=None):
    """Turn away from the side wall selected at the start of the run."""

    if trace_side == "right":
        return "left"

    if trace_side == "left":
        return "right"

    # Do not guess a turn direction before the following side is known.
    return None


def lock_wall_role_angles(walls):
    """Record wall role names and orientations for the current following segment."""

    role_angles = {
        wall["role"]: float(wall["normal_angle"])
        for wall in walls
        if wall.get("role") in ("left", "front", "right")
    }
    if not role_angles:
        return role_angles

    canonical_angles = {
        "right": 0.0,
        "front": 90.0,
        "left": 180.0
    }
    anchor_role = next(iter(role_angles))
    rotation = (
        role_angles[anchor_role] - canonical_angles[anchor_role]
    )
    for role, canonical_angle in canonical_angles.items():
        role_angles.setdefault(
            role,
            (canonical_angle + rotation) % 360.0
        )

    return role_angles


def apply_locked_wall_roles(walls, role_angles):
    """Preserve wall role names by matching their locked orientations."""

    if not role_angles:
        return

    for wall in walls:
        normal_angle = float(wall["normal_angle"])
        role = min(
            role_angles,
            key=lambda name: min(
                abs(normal_angle - role_angles[name]) % 360.0,
                360.0 - abs(normal_angle - role_angles[name]) % 360.0
            )
        )
        wall["role"] = role
        wall["is_front_wall"] = role == "front"
        wall["is_side_wall"] = role in ("left", "right")
        wall["side"] = role if role in ("left", "right") else None
        wall["front_distance"] = (
            wall["wall_distance"] if role == "front" else None
        )


def turn_angle_for_front_wall(front_wall):
    """Return the angle between forward and the front wall, including turn correction."""

    normal_angle = float(front_wall["normal_angle"]) % 180.0
    detected_angle = min(normal_angle, 180.0 - normal_angle)
    return max(0.0, detected_angle - TURN_ANGLE_REDUCTION)


def turn_by_front_wall(front_wall, direction, target_angle=None):
    """Turn using the pre-turn front-wall measurement and gyro feedback."""

    steering = (
        TURN_STEERING_ANGLE
        if direction == "right"
        else -TURN_STEERING_ANGLE
    )
    if target_angle is None:
        target_angle = turn_angle_for_front_wall(front_wall)
    set_angle(steering)
    start_yaw = get_angle("z")
    started_at = time.monotonic()
    update_turn_viewer(
        True,
        direction,
        target_angle,
        0.0
    )
    dc_motor(TURN_MOTOR_SPEED)

    while True:
        current_yaw = get_angle("z")
        turned_angle = abs(current_yaw - start_yaw)
        update_turn_viewer(
            True,
            direction,
            target_angle,
            turned_angle
        )

        print(
            f"turning {direction}: {turned_angle:.1f}°"
            f" / target: {target_angle:.1f}°",
            end="\r",
            flush=True
        )

        if turned_angle >= target_angle:
            break

        if time.monotonic() - started_at >= TURN_TIMEOUT:
            stop()
            set_angle(0)
            update_turn_viewer(
                False,
                direction,
                target_angle,
                turned_angle
            )
            raise RuntimeError(
                f"{target_angle:.1f}度旋回がタイムアウトしました"
            )

        time.sleep(0.01)

    stop()
    set_angle(0)
    update_turn_viewer(
        False,
        direction,
        target_angle,
        turned_angle
    )
    print(
        f"\n旋回完了: {turned_angle:.1f}°"
        f" / 目標: {target_angle:.1f}°"
        f" / {TURN_END_STOP_SECONDS:.1f}秒停止"
    )
    # time.sleep(TURN_END_STOP_SECONDS)


BUZZER = 19
BLINK_LED = 21
PULSE_LEDS = (16, 20)
LED_TURN_INTERVAL = 0.04
BLINK_LED_BRIGHT_DUTY = 100.0
BLINK_LED_DIM_DUTY = 20.0
PULSE_LED_ON_SECONDS = 0.1
PULSE_LED_OFF_SECONDS = 0.8
PULSE_LED_BRIGHT_DUTY = 100.0
PULSE_LED_DIM_DUTY = 40.0
PULSE_LED_PWM_FREQUENCY = 200
LED_UPDATE_INTERVAL = 0.01
COMPLETE_SIGNAL_SECONDS = 4.0
COMPLETE_FADE_SECONDS = 1.0
COMPLETE_BUZZER_INTERVAL = 0.2
COMPLETE_BUZZER_ON_SECONDS = 0.05

GPIO.setmode(GPIO.BCM)
GPIO.setup(BUZZER, GPIO.OUT)


def run_leds(stop_event, turning_event):
    """Show status on GPIO21 and periodically vary the brightness of GPIO16 and GPIO20."""

    turn_led_on = True
    pulse_led_on = True
    pulse_pwms = [
        GPIO.PWM(pin, PULSE_LED_PWM_FREQUENCY)
        for pin in PULSE_LEDS
    ]
    blink_pwm = GPIO.PWM(BLINK_LED, PULSE_LED_PWM_FREQUENCY)
    blink_pwm.start(BLINK_LED_BRIGHT_DUTY)
    for pwm in pulse_pwms:
        pwm.start(PULSE_LED_BRIGHT_DUTY)

    now = time.monotonic()
    next_turn_toggle_at = now + LED_TURN_INTERVAL
    next_pulse_toggle_at = now + PULSE_LED_ON_SECONDS

    try:
        while not stop_event.is_set():
            now = time.monotonic()
            if turning_event.is_set():
                if now >= next_turn_toggle_at:
                    turn_led_on = not turn_led_on
                    blink_pwm.ChangeDutyCycle(
                        BLINK_LED_BRIGHT_DUTY
                        if turn_led_on
                        else BLINK_LED_DIM_DUTY
                    )
                    next_turn_toggle_at = now + LED_TURN_INTERVAL
            else:
                turn_led_on = True
                blink_pwm.ChangeDutyCycle(BLINK_LED_BRIGHT_DUTY)
                next_turn_toggle_at = now + LED_TURN_INTERVAL

            if now >= next_pulse_toggle_at:
                pulse_led_on = not pulse_led_on
                duty = (
                    PULSE_LED_BRIGHT_DUTY
                    if pulse_led_on
                    else PULSE_LED_DIM_DUTY
                )
                for pwm in pulse_pwms:
                    pwm.ChangeDutyCycle(duty)
                pulse_duration = (
                    PULSE_LED_ON_SECONDS
                    if pulse_led_on
                    else PULSE_LED_OFF_SECONDS
                )
                next_pulse_toggle_at = now + pulse_duration

            if stop_event.wait(LED_UPDATE_INTERVAL):
                break
    finally:
        blink_pwm.stop()
        for pwm in pulse_pwms:
            pwm.stop()
        GPIO.output((BLINK_LED, *PULSE_LEDS), GPIO.LOW)

def buzzer_stop():
    GPIO.output(BUZZER, GPIO.LOW)   # Silence the buzzer.
    
    
def buzzer_sleep():
    GPIO.output(BUZZER, GPIO.HIGH)  # Sound the buzzer.
    time.sleep(0.1)
    GPIO.output(BUZZER, GPIO.LOW)   # Silence the buzzer.


def signal_run_complete():
    """Signal a successful run with an LED fade and buzzer sequence."""

    complete_leds = (*PULSE_LEDS, BLINK_LED)
    complete_pwms = [
        GPIO.PWM(pin, PULSE_LED_PWM_FREQUENCY)
        for pin in complete_leds
    ]
    for pwm in complete_pwms:
        pwm.start(100.0)

    started_at = time.monotonic()
    buzzer_on = False
    try:
        while True:
            elapsed = time.monotonic() - started_at
            if elapsed >= COMPLETE_SIGNAL_SECONDS:
                break

            fade_progress = (
                elapsed % COMPLETE_FADE_SECONDS
            ) / COMPLETE_FADE_SECONDS
            duty = 100.0 * (1.0 - fade_progress)
            for pwm in complete_pwms:
                pwm.ChangeDutyCycle(duty)

            should_buzz = (
                elapsed % COMPLETE_BUZZER_INTERVAL
                < COMPLETE_BUZZER_ON_SECONDS
            )
            if should_buzz != buzzer_on:
                buzzer_on = should_buzz
                GPIO.output(
                    BUZZER,
                    GPIO.HIGH if buzzer_on else GPIO.LOW
                )

            time.sleep(LED_UPDATE_INTERVAL)
    finally:
        GPIO.output(BUZZER, GPIO.LOW)
        for pwm in complete_pwms:
            pwm.stop()
        GPIO.output(complete_leds, GPIO.LOW)


def run():
    lidar = LidarReader()
    led_stop_event = Event()
    turning_event = Event()
    led_thread = Thread(
        target=run_leds,
        args=(led_stop_event, turning_event),
        daemon=True,
        name="status-led"
    )
    trace_side = None
    trace_selection_ready_at = None
    planned_turn_angle = None
    turn_count = 0
    final_run_active = False
    final_distance_check_ready_at = None
    locked_role_angles = None
    role_lock_ready_at = None
    front_wall_ignore_until = None
    run_completed = False
    pid = WallPIDController(
        target_distance=TARGET_DISTANCE,
        kp=STEERING_KP,
        ki=STEERING_KI,
        kd=STEERING_KD,
        max_steering_angle=MAX_STEERING_ANGLE,
        integral_limit=INTEGRAL_LIMIT,
    )
    viewer_thread = Thread(
        target=start_viewer_api,
        daemon=True,
        name="lidar-viewer-api"
    )

    try:
        stop()
        set_angle(0)

        GPIO.setmode(GPIO.BCM)
        GPIO.setup(BUZZER, GPIO.OUT)
        GPIO.setup(BLINK_LED, GPIO.OUT, initial=GPIO.LOW)
        GPIO.setup(PULSE_LEDS, GPIO.OUT, initial=GPIO.LOW)

        lidar.start()

        print("ジャイロを初期化中です。ロボットを動かさないでください")
        reset_angle("z")
        update_gyro_viewer()
        print("ジャイロ角度を0°にリセットしました")
        viewer_thread.start()
        print(
            "Live Viewer API: "
            "http://<Raspberry PiのIP>:5000/api/points"
        )
        led_thread.start()
        print("走行を開始します")
        previous_time = time.monotonic()
        # time.sleep(4)
        role_lock_ready_at = time.monotonic() + WALL_ROLE_LOCK_DELAY
        while True:
            current_time = time.monotonic()
            update_gyro_viewer()
            dt = current_time - previous_time
            previous_time = current_time
            points = lidar.get_points()
            detected_walls = detect_walls(points)
            if locked_role_angles is not None:
                apply_locked_wall_roles(
                    detected_walls,
                    locked_role_angles
                )
            elif (
                role_lock_ready_at is not None
                and current_time >= role_lock_ready_at
            ):
                role_angles = lock_wall_role_angles(
                    detected_walls
                )
                if role_angles:
                    locked_role_angles = role_angles
                    apply_locked_wall_roles(
                        detected_walls,
                        locked_role_angles
                    )
                    print(
                        "\n壁の分類名を固定: "
                        f"{locked_role_angles}"
                    )

            front_wall, side_walls = detect_front_and_side_walls(
                points,
                detected_walls=detected_walls
            )
            ignoring_front_wall = (
                front_wall_ignore_until is not None
                and current_time < front_wall_ignore_until
            )
            control_front_wall = None if ignoring_front_wall else front_wall
            update_viewer(
                points,
                detected_walls,
                side_walls
            )
            detected_turn_angle = (
                turn_angle_for_front_wall(control_front_wall)
                if control_front_wall is not None
                else None
            )
            if (
                not final_run_active
                and planned_turn_angle is None
                and control_front_wall is not None
                and detected_turn_angle is not None
                and detected_turn_angle > MIN_TURN_TARGET_ANGLE
                and control_front_wall["front_distance"]
                <= FRONT_WALL_PLAN_DISTANCE
            ):
                planned_turn_angle = detected_turn_angle
                print(
                    "\n旋回角度を確定: "
                    f"{planned_turn_angle:.1f}°"
                    f" / 前壁まで {control_front_wall['front_distance']:.1f} mm"
                )
            target_turn_angle = (
                planned_turn_angle
                if planned_turn_angle is not None
                else detected_turn_angle
            )
            turn_target_is_valid = (
                target_turn_angle is not None
                and target_turn_angle > MIN_TURN_TARGET_ANGLE
            )
            
            if (
                final_run_active
                and final_distance_check_ready_at is not None
                and current_time >= final_distance_check_ready_at
                and control_front_wall is not None
                and control_front_wall["front_distance"]
                <= FINAL_STOP_FRONT_DISTANCE
            ):
                stop()
                set_angle(0)
                print(
                    "\n3周完了後の停止位置に到達: "
                    f"前壁まで {control_front_wall['front_distance']:.1f} mm"
                )
                run_completed = True
                break

            if (
                not final_run_active
                and control_front_wall is not None
                and turn_target_is_valid
                and control_front_wall["front_distance"]
                <= FRONT_WALL_TURN_DISTANCE
            ):
                turn_direction = choose_turn_direction(
                    detected_walls,
                    side_walls,
                    trace_side
                )
                if turn_direction is None:
                    stop()
                    set_angle(0)
                    print(
                        "\n旋回方向を判定できないため停止します"
                    )
                    time.sleep(INTERVAL)
                    continue

                print(
                    "\n前方壁を検出: "
                    f"{control_front_wall['front_distance']:.1f} mm"
                    f" / 壁垂線角度: "
                    f"{control_front_wall['normal_angle']:.1f}°"
                    f" / 旋回方向: {turn_direction}"
                    f" / 目標旋回角度: {target_turn_angle:.1f}°"
                )
                pid.reset()
                locked_role_angles = None
                role_lock_ready_at = None
                turning_event.set()
                try:
                    turn_by_front_wall(
                        control_front_wall,
                        turn_direction,
                        target_turn_angle
                    )
                finally:
                    turning_event.clear()
                front_wall_ignore_until = (
                    time.monotonic()
                    + FRONT_WALL_IGNORE_AFTER_TURN_SECONDS
                )
                role_lock_ready_at = (
                    time.monotonic() + WALL_ROLE_LOCK_DELAY
                )
                turn_count += 1
                print(
                    f"旋回回数: {turn_count} / {MAX_TURN_COUNT}"
                )

                if turn_count >= MAX_TURN_COUNT:
                    final_run_active = True
                    final_distance_check_ready_at = (
                        time.monotonic() + FINAL_RUN_STRAIGHT_SECONDS
                    )
                    print(
                        "3周完了: 旋回後に"
                        f"{FINAL_RUN_STRAIGHT_SECONDS:.1f}秒間"
                        "壁トレースを続けた後、"
                        "前壁との距離による停止判定を開始します: "
                        f"停止距離 {FINAL_STOP_FRONT_DISTANCE} mm"
                    )

                planned_turn_angle = None
                previous_time = time.monotonic()
                continue

            left_wall = side_walls["left"]
            right_wall = side_walls["right"]
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

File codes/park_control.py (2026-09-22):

"""park.py から使う動作部品。距離:mm、角度:度、時間:秒、出力:%。

各走行関数は完了まで待ち、終了・例外時に停止する。
GPIO / LiDAR は使うときに初期化するため、import だけでは動かない。
"""
import math
import threading
import time
from contextlib import contextmanager

from algorithm import detect_walls, detect_front_and_side_walls
from gyro import close_gyro, get_angle, reset_angle

CONTROL_INTERVAL = 0.05
_cancel = threading.Event()
_hardware = None
_lidar = None
_lidar_lock = threading.Lock()
_viewer = None


class ParkingCancelled(Exception):
    """stop_parking() による中断。"""


def _motor():
    global _hardware
    if _hardware is None:
        import newobot
        _hardware = newobot
    return _hardware


def dc_motor(power):
    """newobot.dc_motor と同じ。正:前進、負:後退。"""
    _check_cancel()
    if not math.isfinite(power) or not -100 <= power <= 100:
        raise ValueError("モーター出力は -100〜100 にしてください")
    _motor().dc_motor(power)


def set_angle(angle):
    """newobot.set_angle と同じ。負:左、正:右。"""
    _motor().set_angle(angle)


def stop():
    _motor().stop()


def brake():
    _motor().brake()


def _check_cancel():
    if _cancel.is_set():
        raise ParkingCancelled()


def wait(seconds):
    """直接モーター操作の後にも使える、中断可能な待機。"""
    if not math.isfinite(seconds) or seconds < 0:
        raise ValueError("待機時間は0以上にしてください")
    if _cancel.wait(seconds):
        raise ParkingCancelled()


def pause(seconds=0.4):
    """ブレーキをかけ、ハンドルを中央に戻して待つ。"""
    brake()
    set_angle(0)
    wait(seconds)


@contextmanager
def _movement():
    try:
        _check_cancel()
        yield
    finally:
        try:
            stop()
        finally:
            set_angle(0)


def _positive(value, name):
    if not math.isfinite(value) or value <= 0:
        raise ValueError(f"{name} は0より大きくしてください")


def _yaw():
    angle = get_angle("z")
    if not math.isfinite(angle):
        raise RuntimeError("ジャイロ角度が不正です")
    return angle


class _PD:
    def __init__(self):
        self.error = self.time = None

    def update(self, error, kp, kd, limit, sign=1.0, deadband=0.0):
        now = time.monotonic()
        derivative = 0.0
        if self.time is not None and now > self.time:
            derivative = (error - self.error) / (now - self.time)
        self.error, self.time = error, now
        steering = sign * (kp * error + kd * derivative)
        return 0.0 if abs(error) <= deadband else max(-limit, min(limit, steering))


GYRO_TURN_TIMEOUT = 10.0
GYRO_TURN_MIN_POWER = 22.0       # 発進・目標付近の出力（指定出力を上限にする）
GYRO_TURN_ACCEL_SECONDS = 0.4    # 指定出力まで上げる時間
GYRO_TURN_SLOWDOWN_ANGLE = 25.0  # 残り何度から減速するか
GYRO_TURN_BRAKE_SECONDS = 0.3    # 到達後の電気ブレーキ保持時間
GYRO_TURN_INTERVAL = 0.01       # 旋回時の角度確認周期


def gyro_turn(target_angle, steering_angle, power):
    """固定舵で加減速しながら旋回し、ブレーキ保持後のyawを返す。

    target_angleは最後にreset_angle("z")した時の0°を基準とする符号付き角度。
    現在角度への加算はしない。回る方向はsteering_angleとpowerで決まる。
    ジャイロはこの関数内ではリセットしない。
    """
    _positive(GYRO_TURN_TIMEOUT, "GYRO_TURN_TIMEOUT")
    if not math.isfinite(target_angle):
        raise ValueError("目標角度は有限値にしてください")
    if not math.isfinite(power) or not 0 < abs(power) <= 100:
        raise ValueError("power は0以外の -100〜100 にしてください")
    for value, name in ((GYRO_TURN_ACCEL_SECONDS, "加速時間"),
                        (GYRO_TURN_SLOWDOWN_ANGLE, "減速開始角度"),
                        (GYRO_TURN_INTERVAL, "制御周期")):
        _positive(value, name)
    with _movement():
        start = _yaw()
        started_at = time.monotonic()
        deadline = started_at + GYRO_TURN_TIMEOUT
        maximum = abs(power)
        minimum = min(GYRO_TURN_MIN_POWER, maximum)
        travel_sign = 1 if power > 0 else -1
        while True:
            _check_cancel()
            yaw = _yaw()
            reached = (
                yaw >= target_angle if target_angle >= start else yaw <= target_angle
            )
            if reached:
                # stop()だけでは惰性が残るため、舵を保ったまま電気ブレーキ。
                brake()
                wait(GYRO_TURN_BRAKE_SECONDS)
                return _yaw()
            now = time.monotonic()
            if now >= deadline:
                raise TimeoutError("ジャイロ旋回がタイムアウトしました")
            remaining = abs(target_angle - yaw)
            acceleration = min(1.0, (now - started_at) / GYRO_TURN_ACCEL_SECONDS)
            deceleration = min(1.0, remaining / GYRO_TURN_SLOWDOWN_ANGLE)
            output = minimum + (maximum - minimum) * min(acceleration, deceleration)
            set_angle(steering_angle)
            dc_motor(travel_sign * output)
            wait(GYRO_TURN_INTERVAL)


def gyro_pd(power, duration, target_angle=None, *, kp=1.0, kd=0.1,
            max_steering=30.0, steering_sign=1.0):
    """指定秒数、目標yawをPD制御で保って走る。省略時は開始時の向き。

    指定角度は最後のreset_angle("z")基準。現在角度への加算はしない。
    後退時の操舵反転は自動。steering_sign は機体のジャイロ符号補正用。
    """
    _positive(duration, "duration")
    pd = _PD()
    with _movement():
        target = _yaw() if target_angle is None else target_angle
        deadline = time.monotonic() + duration
        while time.monotonic() < deadline:
            yaw = _yaw()
            sign = steering_sign * (1 if power > 0 else -1)
            set_angle(pd.update(target - yaw, kp, kd, max_steering, sign))
            dc_motor(power)
            wait(min(CONTROL_INTERVAL, max(0, deadline - time.monotonic())))
        return _yaw()


def _read_lidar_frame(detection_range=1500.0):
    """制御とブラウザが同じLiDAR接続を共有する。"""
    global _lidar
    with _lidar_lock:
        _check_cancel()
        if _lidar is None:
            from lidar_read import LidarReader
            _lidar = LidarReader(port="/dev/serial0", baudrate=230400,
                                 scan_frequency_increase_hz=6)
        if not _lidar.running:
            _lidar.start()
        points = _lidar.get_points()
        status = _lidar.get_status()
    walls = detect_walls(points, maximum_distance=detection_range)
    return points, walls, status


def _read_walls(detection_range=1500.0):
    return _read_lidar_frame(detection_range)[1]


def _select_front_wall(walls, final_wall=False):
    if final_wall:
        walls = [
            w for w in walls
            if abs((float(w.get("normal_angle", math.nan)) - 90 + 180) % 360 - 180) <= 40
        ]
    else:
        walls = [w for w in walls if w.get("is_front_wall")]
    return min(walls, key=lambda w: w["wall_distance"], default=None)


def read_front_and_side_walls(*, final_wall=False, detection_range=1500.0):
    """algorithm.pyで同じスキャンから前壁・左壁・右壁を取得する。

    戻り値: (front_wall, side_walls)。未検出の壁はNone。
    side_walls["left"] / side_walls["right"]で横壁を参照する。
    """
    walls = _read_walls(detection_range)
    front_wall, side_walls = detect_front_and_side_walls([], detected_walls=walls)
    if final_wall:
        front_wall = _select_front_wall(walls, final_wall=True)
    return front_wall, side_walls
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

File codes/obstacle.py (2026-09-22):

"""Control the robot during the obstacle challenge.

The run has three main stages:
1. Find a target object with the camera.
2. Avoid objects and black walls while counting blue-line crossings.
3. Stop after the required crossings and challenge-specific finish conditions.
"""

import math
import time

import cv2
import numpy as np
import RPi.GPIO as GPIO

from camera_detector import (
    BOTTOM_EXCLUSION_SIZE,
    PiColorDetector,
    build_primary_target_line,
    object_front_priority,
)
from gyro import get_angle, reset_angle, close_gyro
# from ultrasound import us_get, dis_get, us_back_get, dis_back_get

from buzzer import buzzer_start, buzzer_stop, buzzer_sleep, hurt_beats
from button import button_sleep
from lidar_read import LidarReader
from lidar_wall_follow import follow_wall_until_front_distance
from park import (
    start_parking_0, start_parking_1, start_parking_2,
    start_parking_3, start_parking_4, start_parking_5, stop_parking,
    start_parking_6, start_parking_7,
)
# Initialize hardware interfaces.
# ---------------------------------------------------------------------------

lidar = LidarReader(scan_frequency_increase_hz=6)

# ---------------------------------------------------------------------------
# Driving settings.
# ---------------------------------------------------------------------------


# Gyro-controlled turns.
GYRO_TURN_TIMEOUT_SECONDS = 20.0  # Maximum duration of a gyro turn, in seconds.


# PD control for object and wall avoidance.
AVOID_GREEN_TARGET_ANGLE = -40  # Target line angle when avoiding a green object, in degrees.
AVOID_RED_TARGET_ANGLE = 45  # Target line angle when avoiding a red object, in degrees.
AVOID_GREEN_TARGET_ANGLE_BELOW_150 = -35  # Green target angle when the object center has Y > 150 pixels.
AVOID_RED_TARGET_ANGLE_BELOW_150 = 40  # Red target angle when the object center has Y > 150 pixels.
AVOID_STEERING_MAX = 30  # Maximum steering angle during object avoidance, in degrees.
AVOID_WALL_STEERING_ANGLE = 30.0  # Fixed steering angle for black-wall avoidance, in degrees.
AVOID_KP = 1.5  # Proportional gain for target-line angle error.
AVOID_KD = 0.1# Derivative gain for changes in target-line angle.
AVOID_HOLD_STEERING_BELOW_Y = 200  # Below this image Y coordinate, drive straight or hold the steering angle.
AVOID_STRAIGHT_ANGLE_TOLERANCE = 5.0  # Drive straight when the target-line angle is within this tolerance, in degrees.
AVOID_WALL_STEERING_UPDATE_MIN = 0.5  # Minimum angle change needed to update wall-avoidance steering, in degrees.
AVOID_POWER_BOOST_STEERING_THRESHOLD = 30  # Steering-angle threshold for increasing motor power, in degrees.
AVOID_POWER_BOOST = 0  # Extra motor power during sharp steering.

# Initial backup check.
BACK_CHECK_AREA_THRESHOLD = 2000  # Minimum object area in pixels required to trigger a backup.
BACK_CHECK_SECONDS = 1.25  # Duration of the backup maneuver, in seconds.


# Blue-line crossing detection.
BLUE_LINE_COOLDOWN_SECONDS = 2.5  # Ignore interval after a crossing to prevent duplicate counts, in seconds.
BLUE_LINE_CROSSING_TARGET = 12  # Required crossing count before checking finish conditions.
BLUE_LINE_CROSSING_TARGET_P = 13  # Required crossing count for obstacle_challenge_p only.
BLUE_LINE_LOST_CONFIRM_SECONDS = 1.5  # Required blue-line absence for direction=0, in seconds.
BLUE_LINE_LOST_CONFIRM_SECONDS_DIRECTION_ONE = 2  # Required blue-line absence for direction=1, in seconds.

# Keep the rear light on throughout the obstacle challenge.
REAR_LIGHT_PIN = 21  # BCM GPIO pin connected to the rear light.

detector = PiColorDetector(
    enable_recording=True,
    detect_boundary_enabled=False,
    detect_court_enabled=True,
    bottom_exclusion_size=BOTTOM_EXCLUSION_SIZE,
)
from newobot import dc_motor, set_angle, stop, brake, cleanup
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

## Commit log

2026-07-24 Add STL File
    [カメラマウント１.stl]
2026-08-20 Create Robots CAD
2026-08-20 Upload CAD Files
    [Ackermann steering geometry.stl, Ackermann stick.stl, Battery holder.stl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]
2026-09-15 Update CAD
    [Ackermann steering geometry.stl, Ackermann stick.stl, Battery holder.stl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]
